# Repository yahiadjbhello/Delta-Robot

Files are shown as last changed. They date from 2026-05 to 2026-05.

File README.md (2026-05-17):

# Closed-Loop Delta Robot with ESP32 & PyQt5 GUI





A state-of-the-art, high-speed closed-loop Delta Robot system powered by an **ESP32 microcontroller** and controlled in real-time via a custom **PyQt5 Desktop GUI**. 

This system integrates real-time forward and inverse kinematics, high-frequency PID trajectory tracking, magnetic rotary encoders (`AS5600`) multiplexed via an I2C switch (`TCA9548A`), and precision stepper motors to execute smooth circular, vertical, or point-to-point pick-and-place paths.

---

## 📸 System Overview

```mermaid
graph TD
    %% Styling
    classDef esp32 fill:#1E1E2E,stroke:#313244,stroke-width:2px,color:#CDD6F4;
    classDef pc fill:#11111B,stroke:#313244,stroke-width:2px,color:#CDD6F4;
    classDef i2c fill:#FAB387,stroke:#EBA0AC,stroke-width:2px,color:#11111B;
    classDef drivers fill:#A6E3A1,stroke:#94E2D5,stroke-width:2px,color:#11111B;
    classDef mech fill:#89B4FA,stroke:#74C7EC,stroke-width:2px,color:#11111B;

    subgraph Desktop PC ["🖥️ Host PC"]
        GUI["PyQt5 Controller Application<br/>(software/gui.py)"]:::pc
    end

    subgraph Microcontroller ["🧠 Embedded Brain (ESP32)"]
        ESP["ESP32 MCU<br/>(firmware/esp32_controller)"]:::esp32
    end

    subgraph I2CBus ["🔌 I2C Feedback Network"]
        MUX["TCA9548A Multiplexer"]:::i2c
        ENC1["AS5600 Encoder (Joint 1)"]:::i2c
        ENC2["AS5600 Encoder (Joint 2)"]:::i2c
        ENC3["AS5600 Encoder (Joint 3)"]:::i2c
    end

    subgraph Actuators ["⚙️ Actuation System"]
        DRV1["A4988 Driver 1"]:::drivers
        DRV2["A4988 Driver 2"]:::drivers
        DRV3["A4988 Driver 3"]:::drivers
        M1["Stepper Motor 1"]:::mech
        M2["Stepper Motor 2"]:::mech
        M3["Stepper Motor 3"]:::mech
    end

    %% Connections
    GUI <-->|"USB Serial (115200 Baud)"| ESP
    ESP -->|"I2C (SDA/SCL)"| MUX
    MUX -->|"Channel 1"| ENC1
    MUX -->|"Channel 2"| ENC2
    MUX -->|"Channel 3"| ENC3
    
    ESP -->|"Step / Dir"| DRV1
    ESP -->|"Step / Dir"| DRV2
    ESP -->|"Step / Dir"| DRV3

    DRV1 --> M1
    DRV2 --> M2
    DRV3 --> M3

    ENC1 -.->|"Magnetic Absolute Feedback"| M1
    ENC2 -.->|"Magnetic Absolute Feedback"| M2
    ENC3 -.->|"Magnetic Absolute Feedback"| M3
```

---

## ✨ Features

- **🚀 Real-Time Desktop Control**: Clean desktop app built with **PyQt5** to fine-tune PID values ($K_p$, $K_i$, $K_d$) and change trajectory shapes on the fly over serial.
- **🔄 Closed-Loop Feedback**: Uses three absolute **AS5600 12-bit magnetic encoders** ($4096$ ticks per revolution) mapped through a **TCA9548A I2C Multiplexer** for precise angular positioning of the main arms.
- **📐 Mathematical Modeling**: Complete embedded C++ implementation of:
  - **Inverse Kinematics (IK)**: Map $(x,y,z)$ coordinates to three joint angles $(\theta_1, \theta_2, \theta_3)$ in microseconds.
  - **Forward Kinematics (FPK)**: Re-calculate the actual position of the end-effector from joint feedback to verify accuracy.
- **📈 Advanced Trajectory Modes**:
  - `CIRCULAR`: Smooth circular trajectory on the XY plane with configurable radius and frequency.
  - `UPDOWN`: Sinusoidal vertical Z-axis movement.
  - `POINT`: Precision point-to-point pick-and-place.

---

## 📂 Repository Structure

The project has been cleaned and structured to meet professional engineering repository standards:

```
Delta_robot_project/
├── .gitignore                      # Excludes temporary IDE & build compilation artifacts
├── LICENSE                         # MIT License
├── README.md                       # High-quality documentation
├── docs/                           # Math manuals and technical publications
│   └── inverse_kinematics_fr.pdf   # Theoretical Inverse Kinematics document (French)
├── firmware/                       # Embedded firmware running on the ESP32
│   └── esp32_controller/           # Main sketch directory (compilable in Arduino IDE)
│       └── esp32_controller.ino    
├── hardware/                       # CAD and electronic hardware assets
│   ├── 3d_models/                  # 3D printable STL mechanical assemblies
│   │   ├── fixed_base.stl          # Base structural frame
│   │   ├── moving_platform.stl     # Movable end-effector platform
│   │   ├── upper_arm.stl           # Active linkage upper arm
│   │   ├── lower_arm.stl           # Passive parallel lower rod linkage
│   │   ├── spherical_joint.stl     # Custom ball-and-socket links
│   │   └── ...                     # Additional structural and motor coupling parts
│   └── datasheets/                 # Complete PDF specifications for components
│       ├── AS5600_encoder_datasheet.pdf
│       ├── stepper_motor_specs.pdf
│       └── images/                 # Hardware diagrams & reference pictures
└── software/                       # Python Desktop GUI dashboard
    ├── gui.py                      # Main control software
    └── requirements.txt            # Python environment packages listing
```

---

## 🔌 Wiring & Electrical Pinout

Since the three **AS5600 encoders** share the same hardware I2C address (`0x36`), the **TCA9548A Multiplexer** is required to route communication selectively.

### 1. I2C Network Connections
| ESP32 Pin | TCA9548A Pin | Device / Sub-Channel | Notes |
| :---: | :---: | :--- | :--- |
| **GPIO 21 (SDA)** | `SDA` | ESP32 I2C Data line | Pull-up resistor recommended |
| **GPIO 22 (SCL)** | `SCL` | ESP32 I2C Clock line | Pull-up resistor recommended |
| — | `SD0` / `SC0` | **AS5600 Encoder 1** | Joint 1 position sensor |
| — | `SD1` / `SC1` | **AS5600 Encoder 2** | Joint 2 position sensor |
| — | `SD2` / `SC2` | **AS5600 Encoder 3** | Joint 3 position sensor |

### 2. Motor Driver Connections
| Joint Axis | Driver Pin | ESP32 GPIO Pin | Function |
| :---: | :---: | :---: | :--- |
| **Joint 1** | `STEP_PIN_1` | **GPIO 18** | Step pulses for Joint 1 driver |
| **Joint 1** | `DIR_PIN_1` | **GPIO 19** | Rotation direction for Joint 1 |
| **Joint 2** | `STEP_PIN_2` | **GPIO 13** | Step pulses for Joint 2 driver |
| **Joint 2** | `DIR_PIN_2` | **GPIO 27** | Rotation direction for Joint 2 |
| **Joint 3** | `STEP_PIN_3` | **GPIO 26** | Step pulses for Joint 3 driver |
| **Joint 3** | `DIR_PIN_3` | **GPIO 25** | Rotation direction for Joint 3 |

---

## 📐 Kinematic Formats & Mathematics

A delta robot consists of a fixed base (radius $s_b$) and a moving platform (radius $s_p$) connected by three articulated parallel link mechanisms. Each mechanism consists of an active upper arm (length $L$) and a passive parallel lower arm (length $l$).

### 1. Geometric Parameters
The variables implemented inside `esp32_controller.ino` represent:
- $L = 0.150\text{ m}$ (Length of the upper arm)
- $l = 0.300\text{ m}$ (Length of the parallel lower arm)
- $s_b = 0.41268\text{ m}$ (Base equilateral triangle width)
- $s_p = 0.086\text{ m}$ (End-effector platform width)

### 2. Inverse Kinematics (IK)
Given a desired position $P(x, y, z)$ of the moving platform, the goal is to calculate the motor angles $\theta_i$ for $i \in \{1, 2, 3\}$.
For each arm, the equation of constraint is represented as:

$$E_i \cos(\theta_i) + F_i \sin(\theta_i) = G_i$$

Where:
- $E_i$ and $F_i$ are geometric parameters dependent on base coordinates, arm direction, and the platform coordinates $x$, $y$, and $z$.
- The system solves for $\theta_i$ analytically using the half-tangent substitution ($t_i = \tan(\theta_i / 2)$):

$$\theta_i = 2 \arctan\left(\frac{-F_i \pm \sqrt{E_i^2 + F_i^2 - G_i^2}}{G_i - E_i}\right)$$

---

## 🚀 Installation & Getting Started

### Prerequisites

1. **Python 3.8+**: Ensure you have Python installed. You can check using:
   ```bash
   python --version
   ```
2. **Arduino IDE**: Install the desktop software, or use **VS Code** with the **PlatformIO** extension.

### Setup Instructions

#### Step 1: Install Python Dependencies
Open your terminal inside the `software/` directory and install the necessary libraries:
```bash
pip install -r software/requirements.txt
```

#### Step 2: Upload Firmware to ESP32
1. Open `firmware/esp32_controller/esp32_controller.ino` in your Arduino IDE.
2. Install the necessary libraries in Arduino IDE via **Library Manager**:
   - `AccelStepper`
   - `PID_v1`
3. Connect your ESP32 board to your PC via a USB cable.
4. Select the appropriate **Port** and board (**ESP32 Dev Module**) in the tools menu.
5. Compile and **Upload** the sketch.

#### Step 3: Run the Desktop GUI
Start the control program using Python:
```bash
python software/gui.py
```
1. Enter your serial COM port (e.g. `COM3` on Windows, or `/dev/ttyUSB0` on Linux/macOS).
2. Tweak your desired parameters ($K_p$, $K_i$, $K_d$, Radius, Update intervals).
3. Click **Send Parameters** to immediately sync the parameters with the hardware.

---

## 📡 Serial Protocol Interface

Communication from the PyQt5 desktop GUI to the ESP32 is based on a clean semicolon-separated string format over $115200\text{ Baud}$:

```text
Kp=40.0;Ki=0.0;Kd=0.125;R=0.200;F=0.500;U=5
```

### Protocol Fields:
- `Kp`: Proportional Gain factor.
- `Ki`: Integral Gain factor.
- `Kd`: Derivative Gain factor.
- `R`: Radius of trajectory (for circular motions).
- `F`: Trajectory frequency (cycles per second).
- `U`: ESP32 control loop update interval in milliseconds.

The ESP32 processes this stream in real-time, adjusts the active PID tuning parameters on-the-fly, and replies with coordinate telemetries:

```text
Q:<setpoint_theta_1>,<setpoint_theta_2>,<setpoint_theta_3>,<measured_theta_1>,<measured_theta_2>,<measured_theta_3>,<target_x>,<target_y>,<target_z>,<calculated_x>,<calculated_y>,<calculated_z>
```

---

## 📜 License

This project is open-source software licensed under the [MIT License](LICENSE). Feel free to use, modify, and distribute it for academic or commercial applications.

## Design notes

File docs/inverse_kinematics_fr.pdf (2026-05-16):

# Chapitre 2

# Modélisation du Robot Delta

## 2.1 Introduction

Ce chapitre a pour objectif de modéliser les différents comportements géométriques, cinématiques du robot Delta en fonction des positions et de vitesses de translation et de rotation ainsi que son comportement énergétique autrement dit le modèle dynamique Directe et Inverse du robot dans l’espace articulaire. Aussi, et dans ce qui suit, nous allons présenter les limites géométriques du robot Delta ainsi que les points de singularités et l’espace de travail qu’on va utiliser au cours de l’élaboration de notre projet.

## 2.2 Robot Delta

Le robot Delta est un mécanisme parallèle composé d’une base fixe et de trois bras reliés à une plateforme mobile. Les robots parallèles sont réputés pour leur précision due à l’absence d’erreurs cumulatives au niveau des articulations. Leur morphologie leur assure également une rigidité remarquable, même avec des structures mobiles allégées. Le robot Delta, avec ses 3 degrés de liberté (DDL), est composé de quatre parties principales : la base, les bras, les avant-bras et l’effecteur final (voir figure 2.1). Chaque moteur, positionné à 120 degrés des autres pour une répartition angulaire optimale (360 degrés au total), est responsable d’un DDL, contribuant à améliorer le contrôle du robot.[4]

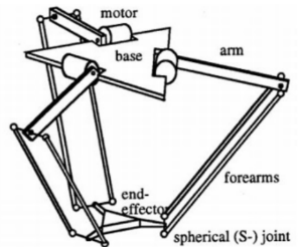
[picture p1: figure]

Figure 2.1 – Schéma du robot Delta

Le choix de la taille des bras et des avant-bras dépend des exigences du projet. Des bras et des avant-bras plus grands permettent de couvrir une surface de travail plus étendue, mais cette relation influence le couple, l’amplitude de mouvement et la vitesse du robot. Le tableau 2.1 illustre ces différences en fonction de la taille du robot. Ce type de mécanisme est couramment utilisé dans l’emballage, la manipulation de composants électroniques, ainsi que dans les industries pharmaceutiques et médicales.[5]

Comparaison entre les tailles du bras et de l’avant-bras
Avant-bras > bras | Avant-bras < bras
Grande amplitude de mouvement | Amplitude de mouvement plus faible
Vitesse plus faible | Vitesse plus élevée
Couple plus élevé | Couple plus faible

Table 2.1 – Relation entre les tailles du bras et de l’avant-bras

### 2.2.1 Le Modèle Géométrique Direct

La modélisation géométrique du robot a pour but de déterminer les relations entre les coordonnées opérationnelles x, y, z et les variables articulaires. Chaque jambe est définie par trois points (voir Figure 2.1), où Bi est le point de connexion entre la base fixe et le i-ème bras, Ai est le point de connexion entre le i-ème bras supérieur et le i-ème bras inférieur, et Pi est le point de connexion entre la plate-forme mobile et le i-ème bras inférieur. [6]

Les dimension de chaque partie sont les suivantes :

- SB : est la longueur latérale de la base fixe
- L : est la longueur du bras (maillon supérieur).
- SF : est la largeur du parallélogramme des jambes de l’avant-bras.
- l : est la longueur de l’avant-bras (bras inférieur).
- SP : est la longueur du côté de la base du mobile.
L’orientation de la plate-forme mobile est toujours identique à celle de la base, donc la matrice de rotation est constante :
B
P
R = I3.

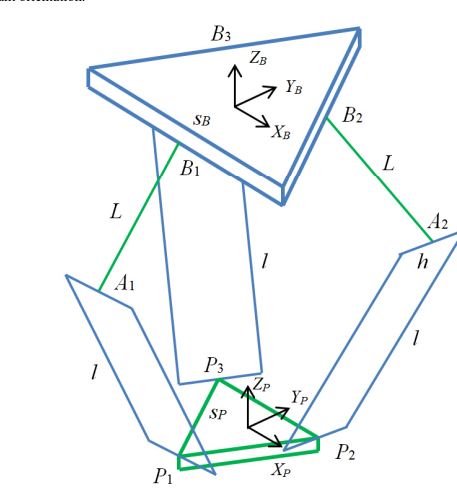
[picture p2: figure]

Figure 2.2 – Diagramme Géométrique du robot Delta

Le repère cartésien fixe de base est noté {B}, dont l’origine est située au centre du triangle équilatéral de la base. Le repère cartésien mobile de la plateforme est noté {P}, dont l’origine est située au centre du triangle équilatéral de la plateforme. L’orientation de {P} est toujours identique à celle de {B}, donc la matrice de rotation B
P R = I3 est
constante. Les variables articulaires sont Θ = {θ1 θ2 θ3}

T
, et les variables cartésiennes sont BPP = {x y z}

T
. Le mécanisme présenté présente une symétrie élevée, avec trois longueurs de jambes supérieures L et trois longueurs inférieures l (les longueurs principales des mécanismes à quatre barres en parallélogramme).

Les détails géométriques de la base fixe et de la plateforme du robot Delta sont présentés ci-dessous :

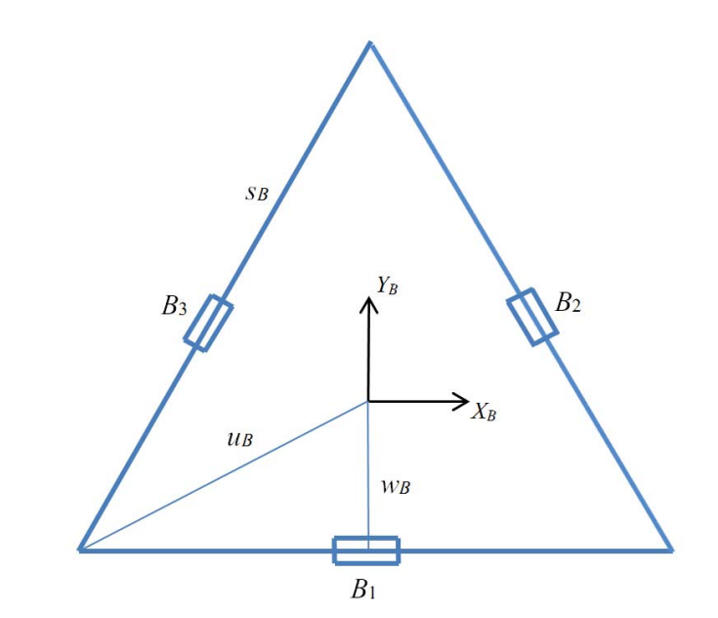
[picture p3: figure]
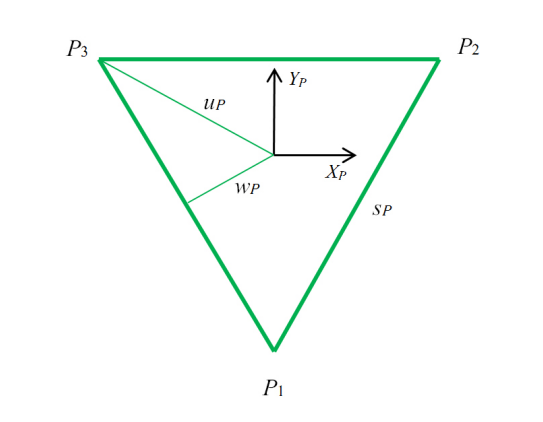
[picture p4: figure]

Figure 2.3 – la plate-forme fixe | Figure 2.4 – la plate-forme mobile

Pour la plate-frorme fixe :

cos 30◦ =

sb
2

×

1
ub

⇒ ub =

√
| 3
| 3 sb

tan 30◦ =

wb
sb/2

⇒ wb =

√
3
6

sb

Pour la plate-frorme mobile :

cos 30◦ =

sp
2

×

1
up

⇒ up =

√
3
3

sp

tan 30◦ =

wp
sp/2

⇒ wp =

√
3
6

sp

On considère
Θ = -
θ1 | θ2 | θ3

T
; p =

x y zT

Ayant aussi les coordonnées des points BBi et P Pi pour i = 1, 2, 3 voir (2.2)

BB1 =

0
−wb
0

BB2 =

√
3
2 wb

1
2wb
0

BB3 =

−

√
3
2 wb

1
2wb
0
- (2.1)

P P1 =

0
−up
0

P P2 =

1/2 sp
wp
0

P P3 =

−
1/2 sp
wp
0
- (2.2)

wb =

√
3
6

sb ub =

√
3
3

sb wp =

√
3
6

sp up =

√
3
3
sp | (2.3)

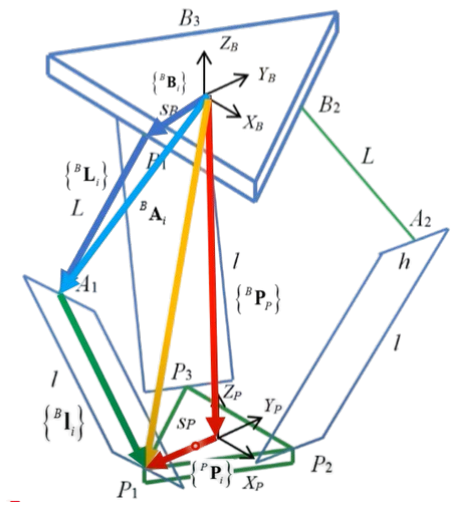
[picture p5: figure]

Figure 2.5 – Diagramme Géométrique du robot Delta.

À partir du diagramme géométrique ci-dessus ( Figure 2.5) :

BAi =

BBi +

BLi | i = 1, 2, 3 : | (2.4)

BPi =

BPp +

pPi | i = 1, 2, 3 : | (2.5)

B
li =

BPi −

BAi | i = 1, 2, 3 : | (2.6)

les trois équations de fermeture sont données par formule suivante :

BBi +

BLi +

B
li =

BPp +
PPi | i = 1, 2, 3 | (2.7)

Où -
B
P R
= [I3] : aucune rotation n’est autorisée par le robot Delta.

B
li =

B
li

=

BPp +

PPi −

BBi −

BLi
, | i = 1, 2, 3 | (2.8)

Il sera plus pratique d’élever au carré les deux côtés des équations de contraintes ci-dessus pour éviter la racine carrée dans les normes euclidiennes.

l

2
i =

B
li

2
= li²
x + li²
y + li²
z
| | (2.9)

En utilisant BPp = [x, y, z]

T
et les valeurs constantes des vecteurs associés aux points Pi et Bi

, qui ont été données précédemment. Les vecteurs BLi dépendent des variables articulaires Θ = [θ1, θ2, θ3]

T
:

BL1 =

0
−L cos θ1
−L sin θ1
- ,

BL2 =

√
3
2

L cos θ2
1/2 L cos θ2
−L sin θ2
- ,

BL3 =

−

√
3
2

L cos θ3
1/2 L cos θ3
−L sin θ3
- (2.10)

B
l1 =

x
y + L cos θ1 + a
z + L sin θ1
- ,

B
l2 =

x −

√
3
2

L cos θ2 + b
y −
1/2 L cos θ2 + c
z + L sin θ2
- ,

B
l3 =

x +

√
3
2

L cos θ3 − b
y −
1/2 L cos θ3 + c
z + L sin θ3

(2.11)
Avec :
a = wb − up

b =

1
2

sp −

√
3
2

wb

c = wp −

1
2

wb

Où :

2L(y + a) cos θ1 + 2zL sin θ1 + x

2 + y

2 + z

2 + a

2 + L

2 + 2ya − l

2 = 0

−L(

√
3(x + b) + y + c) cos θ2 + 2zL sin θ2 + x

2 + y

2 + z

2 + b

2 + c

2 + L

2 + 2xb + 2yc − l

2 = 0

L

√
3(x − b) − y + c
cos θ3 + 2zL sin θ3 + x

2 + y

2 + z

2 + b

2 + c

2 + L

2 + 2xb + 2yc − l

2 = 0
(2.12)

### 2.2.2 Solutions du modèle géométrique inverse

Les trois positions articulaires actionnées Θ =

θ1 | θ2 | θ3

T
sont nécessaires pour pla-cer la plate-forme mobile P (effecteur final) dans la position désirée BPp = [x, y, z]

T
.Ce
problème peut être résolu pour chacune des trois jambes de manière indépendante.La solution du MGI peut être trouvée analytiquement en utilisant les trois équations de contraintes appliquées aux équations de fermeture de la boucle cinématique (dérivées précédemment).

Les trois équations de la cinématique de Position Inverse sont de la forme :

Ei cos θi + Fi sin θi + Gi = 0 | i = 1, 2, 3 | (2.13)

Où
E1 = 2L(y + a)
F1 = 2zL
G1 = x

2 + y

2 + z

2 + a

2 + L

2 + 2ya − l

2

E2 = −L(

√
3(x − b) + y + c)
F2 = 2zL
G2 = x

2 + y

2 + z

2 + b

2 + c

2 + L

2 + 2(xb + yc) − l

| 2

E3 = L(

√
3(x − b) − y − c)
F3 = 2zL
G3 = x

2 + y

2 + z

2 + b

2 + c

2 + L

2 + 2(−xb + yc) − l

| 2

L’équation

Ei cos θi + Fi sin θi + Gi = 0 i = 1, 2, 3 | (2.14)

apparaît souvent dans la cinématique des robots celle-ci est facilement résolue à l’aide de la substitution de la tangente par le demi-angle. Si on définit : ti = tan θi
2
| | ; cos θi = 1−t
| | 2 i 1+t
| | 2 i ;
sin θi =

2ti
1+t

2
i

Ei

1 − t

2
i
1 + t

2
i
+ Fi
2ti
1 + t

2
i
+ Gi = 0 Ei
1 − t

2
i
| + Fi (2ti) + Gi
1 + t

2
i
= 0 (2.15)

(Gi − Ei)t

2
i + (2Fi)ti + (Gi + Ei) = 0 | (2.16)

La forme quadratique :

t1,2 =

−Fi ±

p
E²
i + F

2

i + G²
i
Gi − Ei

(2.17)

la solution du modèle géométrique inverse et donnée par : [7]

θi = 2 tan⁻¹
(ti) | (2.18)

Deux solutions θi résultent du ± dans la formule quadratique. Les deux sont correctes puisqu’il existe deux solutions valides – genou gauche et genou droit. Cela donne deux solutions de branche MGI (Modèle Géométrique Inverse) pour chaque jambe du robot Delta, soit un total de 8 solutions valides possibles. Généralement, la solution où tous les genoux sont orientés vers l’extérieur plutôt que vers l’intérieur sera choisie.

### 2.2.3 Calcul du modèle géométrique direct

Le problème du MGD consiste à calculer la position cartésienne de la plate-forme mobile BPp =

x y zT
en fonction des positions articulaires : Θ = -
θ1 | θ2 | θ3

T
. Le
modèle Géométrique Inverse est généralement plus difficile à résoudre pour les robots parallèles. Ceci nécessite la résolution de plusieurs équations algébriques non linéaires à partir des trois équations de contraintes appliquées au vecteur. Il en résulte généralement plusieurs solutions valides. Heureusement, pour le 3-DDL Delta qui a un mouvement de translation uniquement, le modèle Géométrique Direct pour le robot Delta peut être calculé à l’aide de l’intersection entre les trois sphères. Lorsque l’on visualise ces trois sphères, un point pour le z positif et l’autre pour le z négatif (voir 2.6)

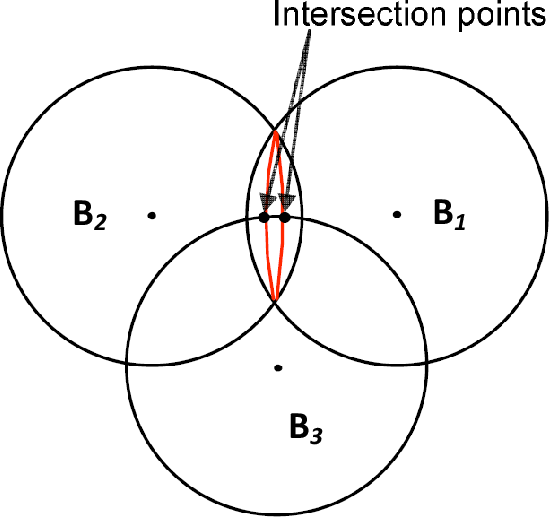
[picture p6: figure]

Figure 2.6 – Deux sphères se coupent en un cercle et une troisième sphère coupe le cercle en deux points.

Pour calculer le MGD du robot Delta, nous déplaçons le centre des trois sphères à l’intérieur des points Ai vers les points virtuels AiAvi

, i = 1, 2, 3 respectivement. Ensuite, la solution du modèle géométrique direct du robot Delta est le point d’intersection des trois sphères.

A⃗
iAvi =

(wb − up) + L cos θi
0
L sin θi
- (2.19)

Avec :

up = A1A1v = A2A2v = A3A3v

qui est la longueur de la distance décalée décrite dans la figure 2.6.

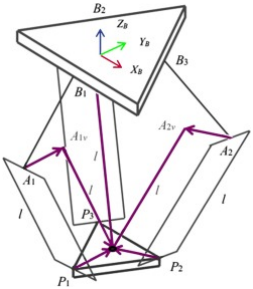
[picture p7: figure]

Figure 2.7 – Schéma MGD du robot Delta

Pour obtenir une matrice qui décrit l’ensemble des trois points du cadre de base O, il faut multiplier Bi par la matrice de rotation R⁰
Z

[8]

R

0
Z =

cos α − sin α 0
sin α | cos α | 0
0 | 0 | 1
- (2.20)

Le résultat de la matrice Av :

A1v

0 = R⁰
ZA1v =

h

S1,x | S2,x | S3,xiT

A2v

0 = R⁰
ZA2v =

h

S1,y | S2,y | S3,yiT

A3v

0 = R⁰
ZA3v =

h

S1,z | S2,z | S3,ziT

(2.21)

On peut alors créer trois sphères dont le rayon est égal à la longueur l que quatre bras, et leurs centres en Bi respectivement. L’équation générale d’une sphère est :

(x − Si,x)

2 + (y − Si,y)

2 + (z − Si,z)

2 = r

2
(2.22)

Cela donne trois équations pour trois jambes i = 1, 2 et 3 respectivement. La première jambe a un bras supérieur qui est parallèle à l’axe x et perpendiculaire à l’axe y, donc l’angle de rotation devient α = 0, comme pour la deuxième et troisième jambe α = 120, α = −120 respectivement.

(x − cos α1[a + cos θ1])² + (y − sin α1[a + L cos θ1])² + (z − L sin θ1)

2 = l

2
(x − cos α2[a + cos θ2])² + (y − sin α2[a + L cos θ2])² + (z − L sin θ2) 2 = l

2
(x − cos α3[a + L cos θ3])² + (y − sin α3[a + L cos θ3])² + (z − L sin θ3)

2 = l

2

(2.23)

Les valeurs des paramètres sont : a = wb − up avec α1 = 0, α2 = 120, α3 = −120.

(x − [a + cos θ1])² + y

2 + (z − L sin θ1)

2 = l

2
x +

1
2

[a + L cos θ2]

2
+

y −

√
3
2

[a + L cos θ2]

!2
+ (z − L sin θ2)

2 = l

2
x −

1
2

[a + L cos θ3]

2
+

y +

√
3
2

[a + L cos θ3]

!2
+ (z − L sin θ3)

2 = l

2

(2.24)

Rearrangeant les équations :

(x + k11)

2 + (y + k12)

2 + (z + k13)

2 = l

2

(x + k21)

2 + (y + k22)

2 + (z + k23)

2 = l

2

(x + k31)

2 + (y + k32)

2 + (z + k33)

2 = l

2

(2.25)

Avec

k11 = a + L cos θ1 | k12 = 0 | k13 = −L sin θ1

k21 =

1/2(a + L cos θ2) k22 =

| −

√
3
2
| | (a + L cos θ2) k23 = −L sin θ1

k31 =

1/2(a + L cos θ3) k32 =

√
3
2
| | (a + L cos θ3) k33 = −L sin θ1

(2.26)

A partir de l’équation (2.26) on obtient

x

2 + y

2 + z

2 + 2ki1x + 2ki2y + 2ki3z = l

2 − (k

2
i1 + k

2
i2 + k

2
i3
) i = 1, 2, 3 | (2.27)

En soustrayant l’équation (2.27) avec i = 2 de l’équation (2.27) avec i = 1, on obtient

2(k11 − k21)x + 2(k12 − k22)y + 2(k13 − k23)z = (k

2
21 + k

2
22 + k

2
23) − (k

2
11 + k

2
12 + k

2
13)
(2.28)

En soustrayant l’équation (2.27) avec i = 3 de l’équation (2.27) avec i = 1, on obtient

2 (k11 − k31) x + 2 (k12 − k32) y + 2 (k13 − k33) z =

k

2
31 + k

2
32 + k

2
33
−
k

2
11 + k

2
12 + k

2
13
(2.29)

On simplifie l’équation (2.28) et l’équation (2.29), on obtient

a1x + b1y + c1z = d1

a2x + b2y + c2z = d2

(2.30)

Avec

a1 = 2 (k11 − k21) | b1 = 2 (k12 − k22) c1 = 2 (k13 − k23)
a2 = 2 (k11 − k31) | b2 = 2 (k12 − k32) c2 = 2 (k13 − k33)

(2.31)

Et

d1 =

k

2
21 + k

2
22 + k

2
23
−
k

2
11 + k

2
12 + k

2
13

d2 =

k

2
31 + k

2
32 + k

2
33
−
k

2
11 + k

2
12 + k

2
13

(2.32)

La matrice à partir de l’équation (2.30) :
a1 | b1
a2 | b2

x
y
=
d1 − c1z
d2 − c2z
(2.33)

On définit :

∆ = a1b2 − a2b1 | (2.34)

Pour ∆ = 0 :

∆x = (d1 − c1z)b2 − (d2 − c2z)b1 = (b2d1 − b1d2) + (b1c2 − b2c1)z

∆y = (d2 − c2z)a1 − (d1 − c1z)a2 = (a1d2 − a2d1) + (a2c1 − a1c2)z

(2.35)

x =

∆x
∆

=

b2d1 − b1d2
∆

+

b1c2 − b2c1
∆

z

y =

∆y
∆

=

a1d2 − a2d1
∆

+

a2c1 − a1c2
∆

z

(2.36)

On considère :

f1 =

b2d1 − b1d2
∆

, f2 =

a1d2 − a2d1
∆

fx =

b1c2 − b2c1
∆

, fy =

a2c1 − a1c2
∆

(2.37)

Donc :

x = f1 + fxz
y = f2 + fyz

(2.38)

En remplaçant l’équation (2.38) dans l’équation (2.25) :

(1 +f

2
x +f

2
y

)z

2 + 2 [(fxf1 + fxk31) + (fyf2 + fyk32) + k33] z +f

2
1 +f

2
2 +k

2
33 −l

2 = 0 (2.39)

On pose :

A = 1 + f

2
x + f

2
y
B = 2 [(fxf1 + fxk31) + (fyf2 + fyk32) + k33]
C = f

2
1 + f

2
2 + k

2
33 − l

2

(2.40)

La solution de ce type d’équation Az² + Bz + C = 0 est de la forme :

z =

−B ±

√
B² − 4AC
2A

(2.41)

Mathématiquement, ni la géométrie directe ni la géométrie inverse ne nous ont donné une solution unique. La raison est due aux angles d’articulations passifs qui existent entre le bras inférieur et le bras supérieur de chaque jambe. Celles-ci ne sont pas déterminées par les équations cinématiques. Il faut donc choisir la solution qui se trouve dans la zone de travail du robot.

— Solution générique : Les deux solutions correspondent à l’intersection d’un cercle et d’une sphère.

— Solution singulière : Une sphère est tangente au cercle d’intersection des deux autres sphères, il n’y a donc qu’une seule solution possible.

— Solution singulière : Le centre de deux sphères coïncide, ce qui donne un nombre infini de solutions. Il s’agit d’une configuration peu probable pour la plupart des réalisations pratiques du manipulateur, sauf dans le cas où θ1 = θ2 = θ3 =

π
2

— Aucune solution : Les trois sphères ne se coupent pas en un point commun [9].

### 2.2.4 Problèmes de singularité

Contrairement aux robots série où les singularités correspondent à une perte de mobi-lité, les robots parallèles comme le Delta présentent des singularités par gain de degrés de liberté. Ce phénomène indésirable compromet le contrôle de la nacelle.
Les singularités provoquent des pertes de contrôle et des efforts mécaniques excessifs. Elles peuvent entraîner des mouvements non désirés de la nacelle ainsi que des couples moteurs très élevés, menaçant à la fois la stabilité du système et l’intégrité des actionneurs. L’analyse statique montre que, près des configurations singulières, les couples moteurs Γ nécessaires pour équilibrer une force appliquée sur la nacelle deviennent très élevés. Le modèle statique s’exprime par :

F = J

−T
- Γ | (2.42)

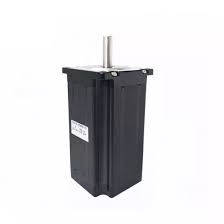
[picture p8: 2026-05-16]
hardware/datasheets/images/stepper_motor.jpg

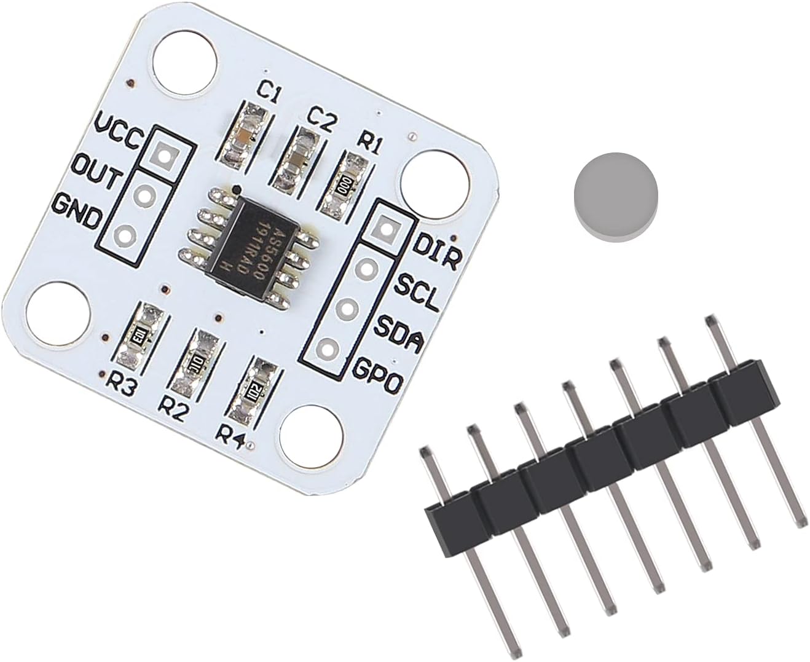
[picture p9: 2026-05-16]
hardware/datasheets/images/AS5600_sensor.jpg

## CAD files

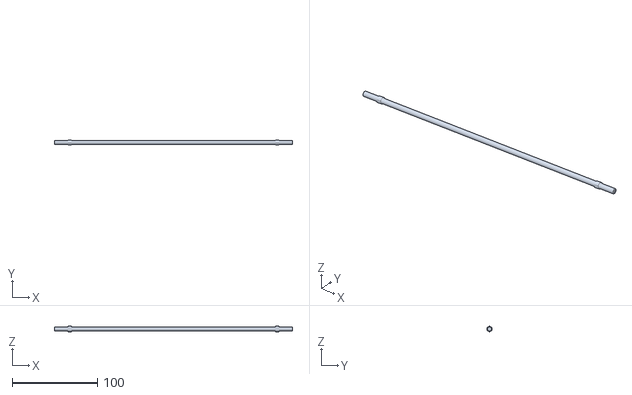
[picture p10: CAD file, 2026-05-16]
hardware/3d_models/lower_arm.stl
280.0 x 5.90 x 6.81

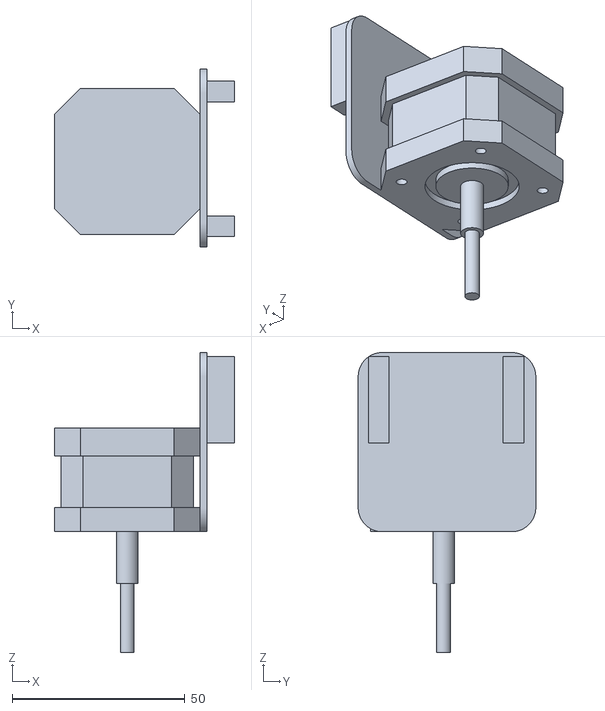
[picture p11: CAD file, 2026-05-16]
hardware/3d_models/motor_mount.stl
52.3 x 51.5 x 87.0

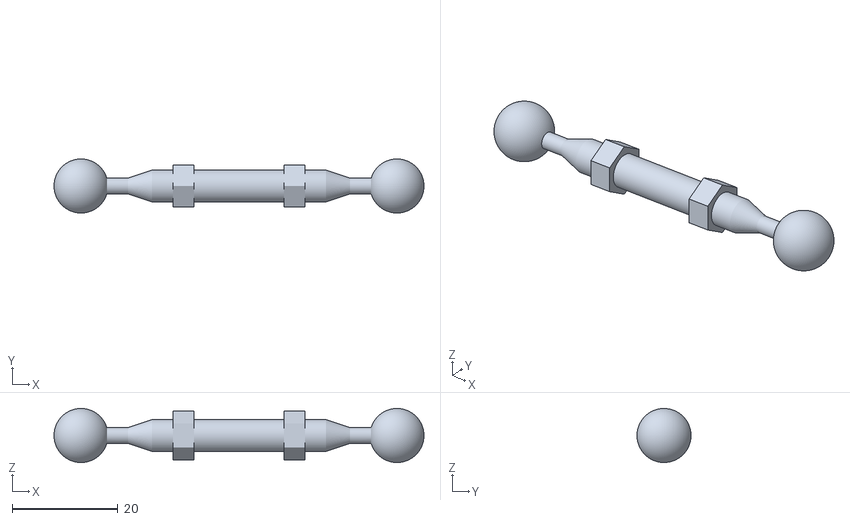
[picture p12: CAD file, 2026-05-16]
hardware/3d_models/horn_1.stl
70.0 x 10.2 x 10.2

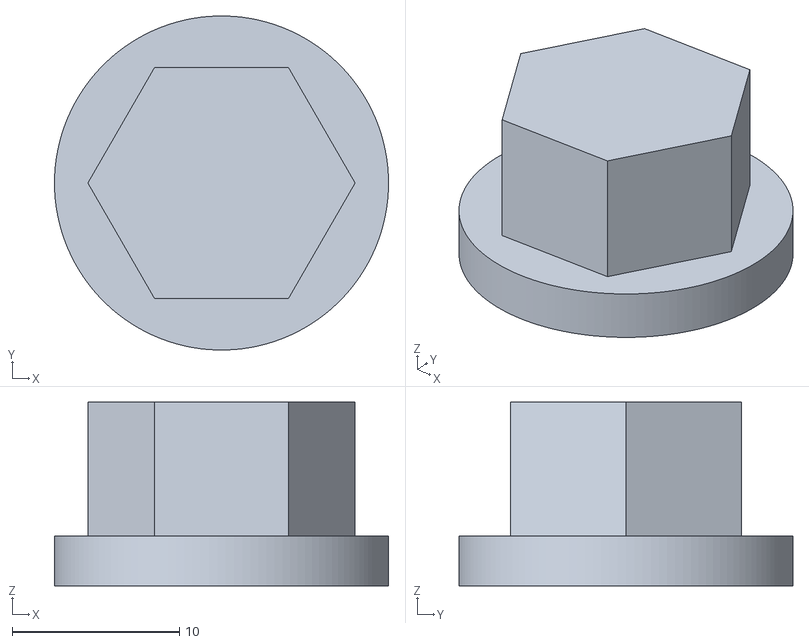
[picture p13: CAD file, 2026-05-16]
hardware/3d_models/origin_axis.stl
20.0 x 20.0 x 11.0

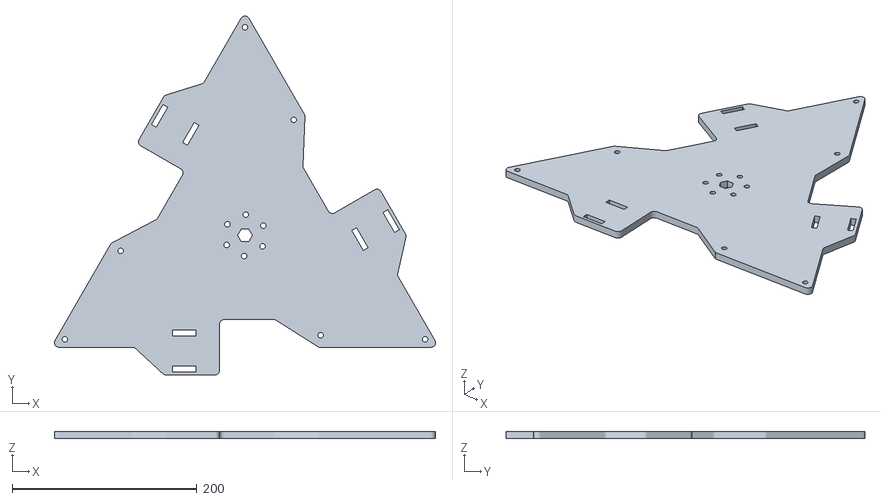
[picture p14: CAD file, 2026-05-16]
hardware/3d_models/fixed_base.stl
412.7 x 388.7 x 8.00

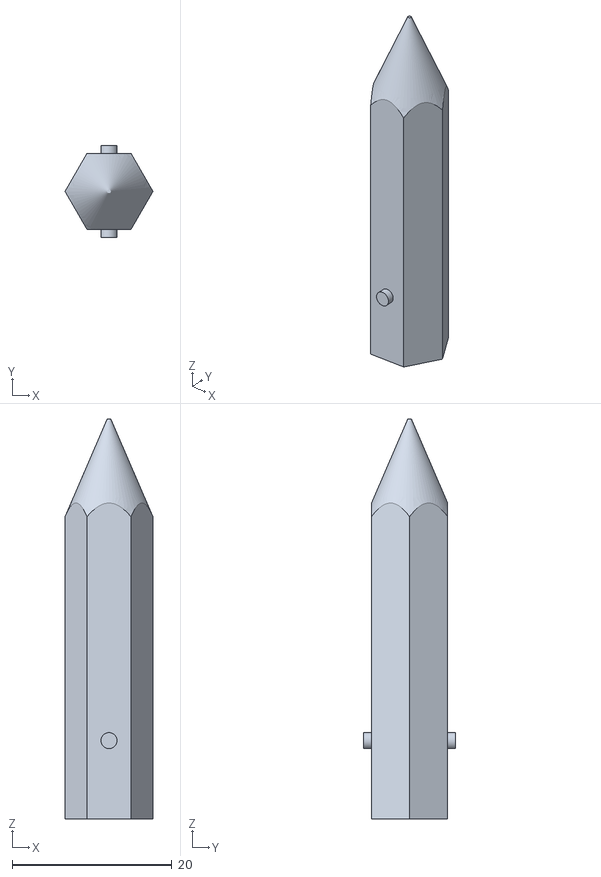
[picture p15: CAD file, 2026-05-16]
hardware/3d_models/end_effector.stl
11.0 x 11.5 x 50.0

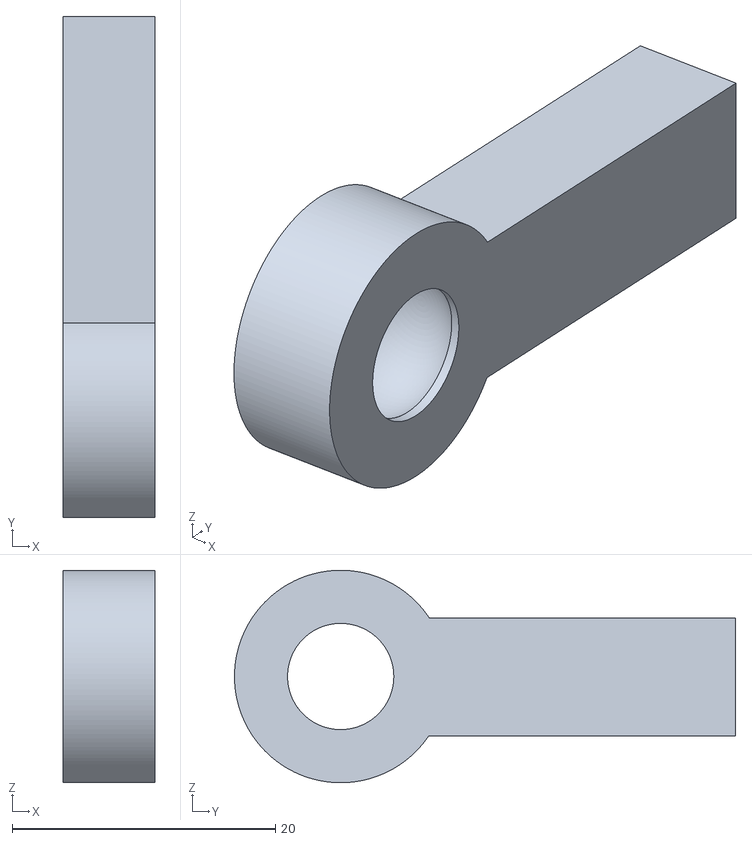
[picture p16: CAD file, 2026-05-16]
hardware/3d_models/spherical_joint.stl
7.00 x 38.1 x 16.1

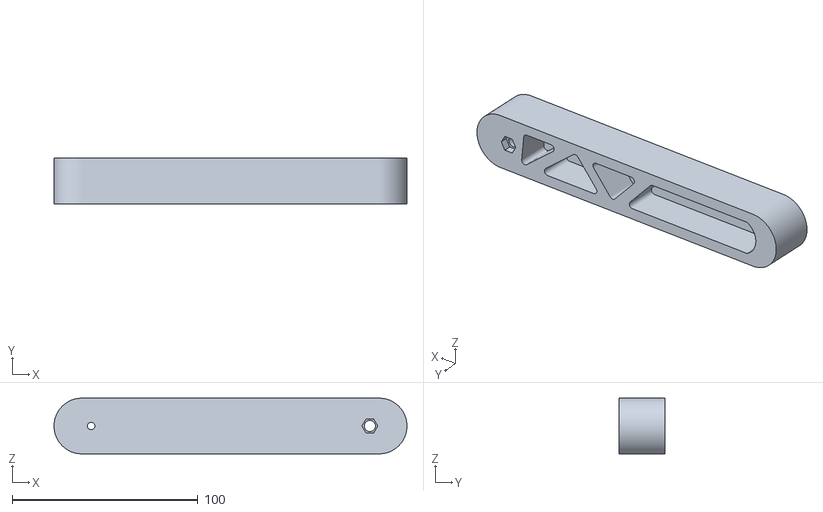
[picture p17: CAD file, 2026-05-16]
hardware/3d_models/upper_arm.stl
190.0 x 25.0 x 30.0

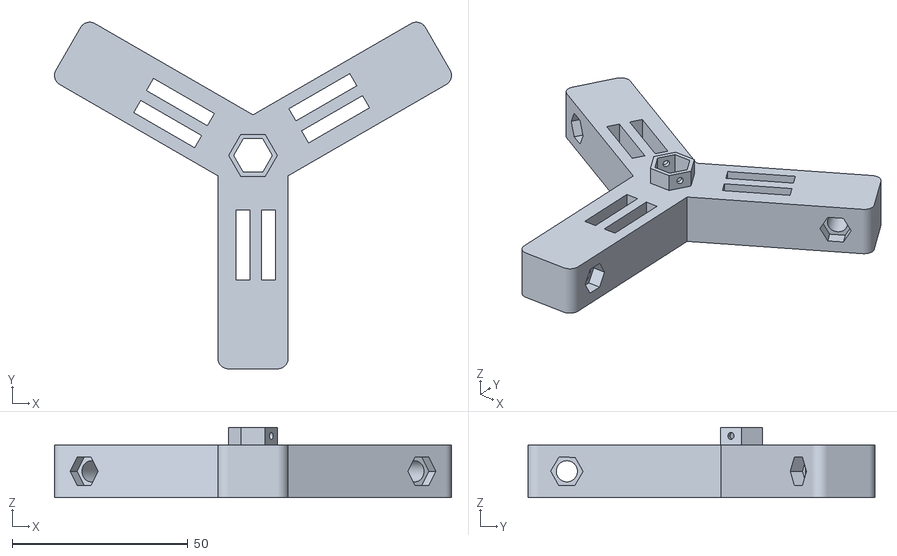
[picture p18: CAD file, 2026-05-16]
hardware/3d_models/moving_platform.stl
112.9 x 98.5 x 20.0

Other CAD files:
hardware/3d_models/horn_2.stl

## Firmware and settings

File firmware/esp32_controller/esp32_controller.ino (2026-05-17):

// Delta Robot ESP32 with Forward Kinematics + GUI Communication (Fixed)
#include <Wire.h>
#include <AccelStepper.h>
#include <PID_v1.h>
#include <math.h>

// === AS5600 + TCA9548A ===
#define AS5600_ADDR 0x36
#define TCA_ADDR 0x70
#define SDA_PIN 21
#define SCL_PIN 22

// === Stepper Motor Pins ===
#define STEP_PIN_1 18
#define DIR_PIN_1 19
#define STEP_PIN_2 13
#define DIR_PIN_2 27
#define STEP_PIN_3 26
#define DIR_PIN_3 25

AccelStepper stepper1(AccelStepper::DRIVER, STEP_PIN_1, DIR_PIN_1);
AccelStepper stepper2(AccelStepper::DRIVER, STEP_PIN_2, DIR_PIN_2);
AccelStepper stepper3(AccelStepper::DRIVER, STEP_PIN_3, DIR_PIN_3);

// === PID Control ===
double input[3] = {0}, output[3] = {0}, setpoint[3] = {0};
double Kp = 40.0, Ki = 0.0, Kd = 0.125;
PID pid1(&input[0], &output[0], &setpoint[0], Kp, Ki, Kd, DIRECT);
PID pid2(&input[1], &output[1], &setpoint[1], Kp, Ki, Kd, DIRECT);
PID pid3(&input[2], &output[2], &setpoint[2], Kp, Ki, Kd, DIRECT);

int motorSign[3] = {1, 1, 1};
double filteredInput[3] = {0};
const float alpha = 0.8;

// === Trajectory Control ===
String MODE = "CIRCULAR";
float RADIUS = 0.2;
float FREQUENCY = 0.5;
int UPDATE_INTERVAL = 5;
float ALTITUDE = 0.1;
float currentAngle = 0.0;
float pickPoint[3] = {0, 0, -0.3};
float placePoint[3] = {0.1, 0.1, -0.3};

unsigned long startTime;
unsigned long lastUpdate = 0;

void setup() {
  Serial.begin(115200);
  Wire.begin(SDA_PIN, SCL_PIN, 400000);
  startTime = millis();

  stepper1.setMaxSpeed(3000); stepper1.setAcceleration(400);
  stepper2.setMaxSpeed(3000); stepper2.setAcceleration(400);
  stepper3.setMaxSpeed(3000); stepper3.setAcceleration(400);

  pid1.SetMode(AUTOMATIC); pid1.SetOutputLimits(-3000, 3000);
  pid2.SetMode(AUTOMATIC); pid2.SetOutputLimits(-3000, 3000);
  pid3.SetMode(AUTOMATIC); pid3.SetOutputLimits(-3000, 3000);

  Serial.println("System Ready - Real-Time GUI Communication");
}

void loop() {
  handleSerialInput();
  unsigned long now = millis();

  if (now - lastUpdate >= UPDATE_INTERVAL) {
    lastUpdate = now;

    float x = 0, y = 0, z = -0.3;
    if (MODE == "CIRCULAR") {
      x = RADIUS * cos(currentAngle);
      y = RADIUS * sin(currentAngle);
    } else if (MODE == "UPDOWN") {
      x = 0;
      y = 0;
      z = -0.3 + ALTITUDE * sin(currentAngle);
    } else if (MODE == "POINT") {
      x = pickPoint[0];
      y = pickPoint[1];
      z = pickPoint[2];
    }

    currentAngle += 2 * PI * FREQUENCY * (UPDATE_INTERVAL / 1000.0);
    if (currentAngle > 2 * PI) currentAngle -= 2 * PI;

    double q_deg[3];
    computeInverseKinematics(x, y, z, q_deg);

    for (int i = 0; i < 3; i++) {
      setpoint[i] = q_deg[i];
      filteredInput[i] = alpha * wrapTo180(readAngleFromChannel(3 - i)) + (1 - alpha) * filteredInput[i];
      input[i] = filteredInput[i];
    }

    pid1.Compute(); pid2.Compute(); pid3.Compute();
    applyPID(stepper1, motorSign[0] * output[0]);
    applyPID(stepper2, motorSign[1] * output[1]);
    applyPID(stepper3, motorSign[2] * output[2]);

    float xyz_mes[3];
    fpk(radians(filteredInput[0]), radians(filteredInput[1]), radians(filteredInput[2]), xyz_mes);

    Serial.print("Q:");
    for (int i = 0; i < 3; i++) Serial.print(setpoint[i]), Serial.print(",");
    for (int i = 0; i < 3; i++) Serial.print(filteredInput[i]), Serial.print(",");
    Serial.printf("%.3f,%.3f,%.3f,", x, y, z);
    for (int i = 0; i < 3; i++) Serial.print(xyz_mes[i], 3), Serial.print(i < 2 ? "," : "\n");
  }

  stepper1.runSpeed();
  stepper2.runSpeed();
  stepper3.runSpeed();
}

void parseAndUpdateParams(String line) {
  int start = 0;
  while (start < line.length()) {
    int end = line.indexOf(';', start);
    if (end == -1) end = line.length();
    int sep = line.indexOf('=', start);
    if (sep != -1 && sep < end) {
      String key = line.substring(start, sep);
      String val = line.substring(sep + 1, end);
      float fval = val.toFloat();
      if (key == "Kp") { Kp = fval; pid1.SetTunings(Kp, Ki, Kd); pid2.SetTunings(Kp, Ki, Kd); pid3.SetTunings(Kp, Ki, Kd); }
      else if (key == "Ki") { Ki = fval; pid1.SetTunings(Kp, Ki, Kd); pid2.SetTunings(Kp, Ki, Kd); pid3.SetTunings(Kp, Ki, Kd); }
      else if (key == "Kd") { Kd = fval; pid1.SetTunings(Kp, Ki, Kd); pid2.SetTunings(Kp, Ki, Kd); pid3.SetTunings(Kp, Ki, Kd); }
      else if (key == "R")  { RADIUS = fval; }
      else if (key == "F")  { FREQUENCY = fval; }
      else if (key == "U")  { UPDATE_INTERVAL = (int)fval; }
      else if (key == "Z")  { ALTITUDE = fval; }
      else if (key == "MODE") { MODE = val; }
      else if (key == "PICK") {
        sscanf(val.c_str(), "%f,%f,%f", &pickPoint[0], &pickPoint[1], &pickPoint[2]);
      } else if (key == "PLACE") {
        sscanf(val.c_str(), "%f,%f,%f", &placePoint[0], &placePoint[1], &placePoint[2]);
      }
    }
    start = end + 1;
  }
}

void applyPID(AccelStepper &stepper, double speed) {
  stepper.setSpeed(fabs(speed) < 3 ? 0 : -speed);
}

void selectTCAChannel(uint8_t channel) {
  if (channel > 7) return;
  Wire.beginTransmission(TCA_ADDR);
  Wire.write(1 << channel);
  Wire.endTransmission();
  delayMicroseconds(300);
}

float readAngleFromChannel(uint8_t ch) {
  selectTCAChannel(ch);
  return getAngleDegrees();
}

uint16_t readAS5600RawAngle() {
  Wire.beginTransmission(AS5600_ADDR);
  Wire.write(0x0C);
  Wire.endTransmission(false);
  Wire.requestFrom(AS5600_ADDR, 2);
  if (Wire.available() == 2) {
    uint8_t msb = Wire.read();
    uint8_t lsb = Wire.read();
    return (msb << 8) | lsb;
  }
  return 0;
}

float getAngleDegrees() {
  return (readAS5600RawAngle() * 360.0) / 4096.0;
}

float wrapTo180(float angle) {
  while (angle > 180.0) angle -= 360.0;
  while (angle < -180.0) angle += 360.0;
  return angle;
}
void handleSerialInput() {
  static String inputLine;  // Buffer to store incoming serial bytes

  while (Serial.available()) {
    char c = Serial.read();
    if (c == '\n') {
      parseAndUpdateParams(inputLine);
      inputLine = "";  // Clear buffer after processing
    } else {
      inputLine += c;
    }
  }
}


void computeInverseKinematics(float x, float y, float z, double q_deg[3]) {
  const float sb = 0.41268, sp = 0.086, L = 0.150, l = 0.3;
  float wb = sb * sqrt(3.0) / 6.0, wp = sp * sqrt(3.0) / 6.0, up = sp * sqrt(3.0) / 3.0;
  float a = wb - up;
  float b = sp / 2.0 - sqrt(3.0) / 2.0 * wb;
  float c = wp - wb / 2.0;

  float H[3], G[3], F[3], t[3], q[3];
  H[0] = 2.0 * L * (y + a);
  H[1] = -L * (sqrt(3.0) * (x + b) + y + c);
  H[2] = L * (sqrt(3.0) * (x - b) - y - c);

  G[0] = x * x + y * y + z * z + a * a + L * L + 2.0 * y * a - l * l;
  G[1] = x * x + y * y + z * z + b * b + c * c + L * L + 2.0 * (x * b + y * c) - l * l;
  G[2] = x * x + y * y + z * z + b * b + c * c + L * L + 2.0 * (-x * b + y * c) - l * l;

  F[0] = F[1] = F[2] = 2.0 * z * L;

  for (int i = 0; i < 3; i++) {
    float delta = H[i] * H[i] + F[i] * F[i] - G[i] * G[i];
    if (delta < 0) q_deg[i] = 0;
    else {
      t[i] = (-F[i] + sqrt(delta)) / (G[i] - H[i]);
      q[i] = 2.0 * atan(t[i]);
      q_deg[i] = (q[i] * 180.0 / PI) - 175.83;
    }
  }
}
// === Rotation around Z Axis ===
void rot_0Z(float angle, float R[3][3]) {
  R[0][0] = cos(angle);  R[0][1] = -sin(angle); R[0][2] = 0;
  R[1][0] = sin(angle);  R[1][1] =  cos(angle); R[1][2] = 0;
  R[2][0] = 0;           R[2][1] = 0;           R[2][2] = 1;
}

// === Apply Rotation to Vector ===
void applyRotation(float R[3][3], float v[3], float result[3]) {
  for (int i = 0; i < 3; i++) {
    result[i] = R[i][0]*v[0] + R[i][1]*v[1] + R[i][2]*v[2];
  }
}

// === Forward Kinematics (FPK) for Delta Robot ===
bool fpk(float th1, float th2, float th3, float P[3]) {
  const float sb = 0.41268;
  const float sp = 0.086;
  const float L  = 0.150;
  const float l  = 0.300;
  const float pi = M_PI;
  th1 =th1+radians(175.83);
  th2 =th2+radians(175.83);
  th3 =th3+radians(175.83);
  float wb = sb * sqrt(3.0) / 6.0;
  float wp = sp * sqrt(3.0) / 6.0;
  float up = sp * sqrt(3.0) / 3.0;

  // Active arm vector linkages in base frame
  float e1[3] = {(wb - up) + L * cos(th1), 0, -L * sin(th1)};
  float e2[3] = {(wb - up) + L * cos(th2), 0, -L * sin(th2)};
  float e3[3] = {(wb - up) + L * cos(th3), 0, -L * sin(th3)};

  float E1[3], E2[3], E3[3], R[3][3];
  rot_0Z(0, R);            applyRotation(R, e1, E1);
  rot_0Z(2*pi/3, R);       applyRotation(R, e2, E2);
  rot_0Z(4*pi/3, R);       applyRotation(R, e3, E3);

  float M[3][3] = {
    {E1[0], E1[1], E1[2]},
    {E2[0], E2[1], E2[2]},
    {E3[0], E3[1], E3[2]}
  };

  float M1[3][3];
  for (int i = 0; i < 3; i++)
    for (int j = 0; j < 3; j++)
      M1[i][j] = -M[i][j];

  float N[2][3], V[2];
  for (int i = 0; i < 2; i++) {
    for (int j = 0; j < 3; j++) {
      N[i][j] = 2 * (M1[0][j] - M1[i + 1][j]);
    }
    V[i] = (pow(M1[i + 1][0], 2) + pow(M1[i + 1][1], 2) + pow(M1[i + 1][2], 2))
         - (pow(M1[0][0], 2) + pow(M1[0][1], 2) + pow(M1[0][2], 2));
  }

  float D = N[0][0]*N[1][1] - N[1][0]*N[0][1];
  if (fabs(D) < 1e-6) return false;

  float f1 = (N[1][1]*V[0] - N[0][1]*V[1]) / D;
  float f2 = (N[0][0]*V[1] - N[1][0]*V[0]) / D;
  float f3 = (N[0][1]*N[1][2] - N[0][2]*N[1][1]) / D;
  float f4 = (N[1][0]*N[0][2] - N[0][0]*N[1][2]) / D;

  float E = f3*f3 + f4*f4 + 1;
  float F = 2*M1[2][2] + 2*f3*(f1 + M1[2][0]) + 2*f4*(f2 + M1[2][1]);
  float G = pow(f1 + M1[2][0], 2) + pow(f2 + M1[2][1], 2) + pow(M1[2][2], 2) - l*l;

  float delta = F*F - 4*E*G;
  if (delta < 0) return false;

  float z = (-F - sqrt(delta)) / (2*E);
  float x = f1 + f3 * z;
  float y = f2 + f4 * z;

  float rawP[3] = {x, y, z};
  rot_0Z(-pi / 2, R);
  applyRotation(R, rawP, P);

  return true;
}

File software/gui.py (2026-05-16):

import sys
import serial
from PyQt5.QtWidgets import (
    QApplication, QWidget, QLabel, QVBoxLayout, QPushButton,
    QLineEdit, QMessageBox, QHBoxLayout
)
from PyQt5.QtCore import Qt

class DeltaControlGUI(QWidget):
    def __init__(self):
        super().__init__()
        self.initUI()
        self.serial_port = None

    def initUI(self):
        self.setWindowTitle("Delta Robot - Real-Time Control")

        self.port_label = QLabel("Serial Port (e.g. COM3 or /dev/ttyUSB0):")
        self.port_input = QLineEdit()

        # === Input Fields ===
        self.kp_input = self.create_input("Kp", "40.0")
        self.ki_input = self.create_input("Ki", "0.0")
        self.kd_input = self.create_input("Kd", "0.125")
        self.radius_input = self.create_input("Radius", "0.2")
        self.freq_input = self.create_input("Frequency", "0.5")
        self.update_input = self.create_input("Update Interval", "5")

        # === Send Button ===
        self.send_button = QPushButton("Send Parameters")
        self.send_button.clicked.connect(self.send_parameters)

        # === Layout ===
        layout = QVBoxLayout()
        layout.addWidget(self.port_label)
        layout.addWidget(self.port_input)
        for label, field in self.inputs:
            layout.addWidget(label)
            layout.addWidget(field)
        layout.addWidget(self.send_button)

        self.setLayout(layout)

    def create_input(self, name, default):
        label = QLabel(f"{name}:")
        input_field = QLineEdit()
        input_field.setText(default)
        if not hasattr(self, 'inputs'):
            self.inputs = []
        self.inputs.append((label, input_field))
        return input_field

    def send_parameters(self):
        port = self.port_input.text().strip()
        if not port:
            QMessageBox.warning(self, "Error", "Please enter a valid serial port.")
            return

        try:
            if self.serial_port is None or not self.serial_port.is_open:
                self.serial_port = serial.Serial(port, 115200, timeout=1)

            # Read user input values
            params = {
                "Kp": float(self.kp_input.text()),
                "Ki": float(self.ki_input.text()),
                "Kd": float(self.kd_input.text()),
                "R": float(self.radius_input.text()),
                "F": float(self.freq_input.text()),
                "U": int(self.update_input.text())
            }

            # Format and send
            message = ";".join([f"{k}={v}" for k, v in params.items()]) + "\n"
            self.serial_port.write(message.encode())
            print("Sent:", message)

        except ValueError:
            QMessageBox.critical(self, "Input Error", "Please enter valid numeric values.")
        except serial.SerialException as e:
            QMessageBox.critical(self, "Serial Error", str(e))

if __name__ == '__main__':
    app = QApplication(sys.argv)
    window = DeltaControlGUI()
    window.show()
    sys.exit(app.exec_())
